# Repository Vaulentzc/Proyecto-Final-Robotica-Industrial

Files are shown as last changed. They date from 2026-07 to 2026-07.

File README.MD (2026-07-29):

<div align="center">
<picture>
    <source srcset="https://imgur.com/5bYAzsb.png" media="(prefers-color-scheme: dark)">
    <source srcset="https://imgur.com/Os03JoE.png" media="(prefers-color-scheme: light)">
    Escudo UNAL
</picture>

<h3>Curso de Robótica 2026-I</h3>

<h1>Proyecto Final - Robótica Industrial</h1>

<h2>Profesores: <br>Pedro Fabián Cárdenas Herrera <br> Manuel Felipe Carranza Montenegro<br></h2>

<p>
  
  
  
</p>

<br>
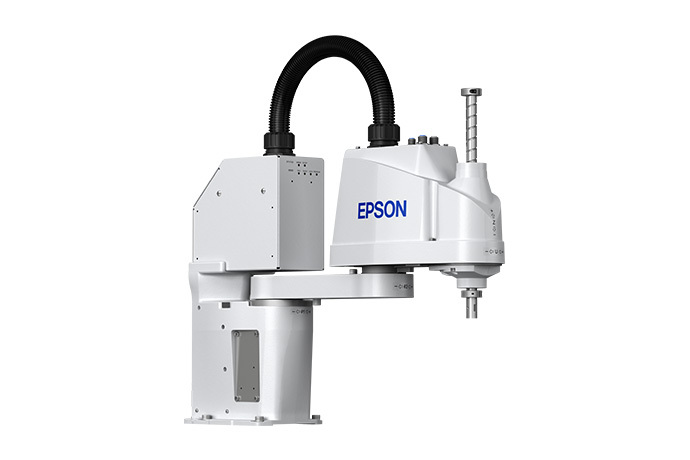
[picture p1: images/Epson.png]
Epson
<br>
<b>Figura 1. Manipulador industrial EPSON T3-401S.</b>
</div>

</div>

# Integrantes
1. Juan Andrés Moreno Benavides [jumorenobe@unal.co](Jumorenobe)
2. Mateo Ramos Cujer [mramoscu@unal.edu.co](MateoKGR)
3. Paula Valentina Alvarez Chaparro [palvarezch@unal.edu.co] (Vaulentzc)
4. Yesid Camilo Ojeda Hernández [yojeda@unal.edu.co] (YojedaMt)
5. David Felipe Cardenas Cubides [dcardenascu@unal.edu.co] (dcardenascu)

# Índice

1. [Bitácora del desarrollo](#1-bitácora-del-desarrollo)
2. [Diagrama de flujo del proceso global](#2-diagrama-de-flujo-del-proceso-global)
3. [Diseño del gripper](#3-diseño-del-gripper)
4. [Simulación](#4-simulación)
5. [Código fuente](#5-código-fuente)
6. [Comparación manual vs automatizado](#6-comparación-manual-vs-automatizado)
7. [Descripción detallada de la solución](#7-descripción-detallada-de-la-solución)
8. [Diagrama de flujo acciones del robot](#8-diagrama-de-flujo-acciones-del-robot)
9. [Plano de planta](#9-plano-de-planta)
10. [Videos demostrativos](#10-videos-demostrativos)

## 1. Bitácora del desarrollo

A continuación se documenta el proceso cronológico de diseño, simulación, fabricación e integración en laboratorio para el desarrollo de la **Etapa 2: Ensamblaje de Componentes** con el robot **Epson T3 401S ("Junior")**.

---

### Fase 1: Definición de Requerimientos y Diseño Mecánico

#### Definición de requerimientos

El objetivo principal de la herramienta es permitir la manipulación automática de componentes electrónicos mediante un brazo robótico, siendo capaz de recoger una pieza desde una ubicación determinada y depositarla en otra con la mayor precisión posible. Debido a que la aplicación está orientada al manejo de componentes para PCB, resulta especialmente importante mantener la orientación de la pieza durante todo el proceso, ya que una rotación indeseada dificultaría o impediría su colocación correcta.

A partir de estos objetivos se definieron los siguientes requerimientos de diseño:

- Ser capaz de levantar componentes electrónicos de diferentes tamaños.
- Poder activarse y desactivarse mediante una señal de control.
- Mantener la orientación del componente durante el transporte, en la medida de lo posible.
- Tener un diseño mecánico sencillo para facilitar tanto su fabricación como su integración con el brazo robótico.
- Minimizar la complejidad de la simulación y del sistema de control.

Con estos criterios se evaluaron distintas alternativas para la herramienta de agarre.

---

#### Alternativa 1: Ventosa de vacío

La primera opción considerada fue una **ventosa de vacío**, accionada mediante un sistema electroneumático. Esta alternativa presentaba la ventaja de que el laboratorio ya disponía de una herramienta funcional, reduciendo considerablemente el tiempo de diseño y fabricación.

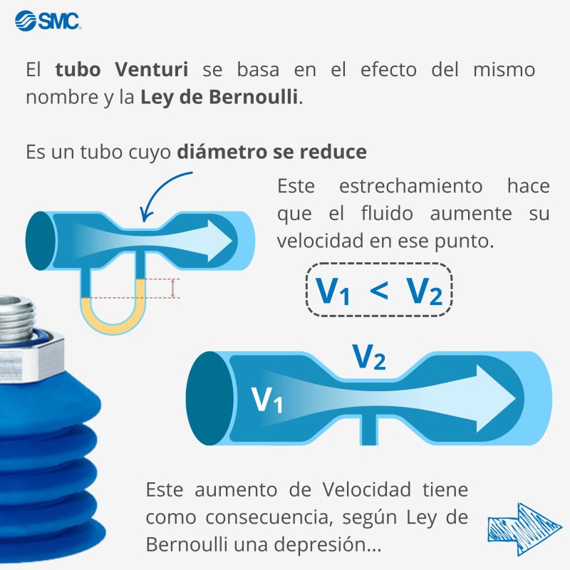
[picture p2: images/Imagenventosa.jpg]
Ventosa


Entre sus principales ventajas se encuentran:

- Diseño ya disponible y probado.
- Activación sencilla mediante electroválvulas.
- Integración relativamente simple con el sistema de control.
- Capacidad de manipular componentes de diferentes materiales.

Sin embargo, durante el análisis se identificaron varias limitaciones importantes para la aplicación propuesta.

La fuerza de succión se distribuye sobre una superficie relativamente amplia, lo que hace que el punto exacto de contacto dependa de la geometría de la pieza. Además, durante el momento en que la ventosa entra en contacto con el componente es frecuente que éste gire o cambie ligeramente de posición antes de quedar completamente adherido.

Como consecuencia, la orientación final del componente resulta poco repetible, lo cual representa una desventaja significativa cuando posteriormente debe colocarse sobre una PCB con una orientación específica.

Por estas razones, aunque la ventosa constituye una solución robusta para tareas generales de manipulación, no se consideró la alternativa más adecuada para este proyecto.

---

#### Alternativa 2: Electroimán

La segunda alternativa consistió en diseñar una herramienta basada en un **electroimán**.

Un electroimán funciona aprovechando el fenómeno del **electromagnetismo**: cuando una corriente eléctrica circula por una bobina, se genera un campo magnético capaz de atraer materiales ferromagnéticos. Al interrumpir la corriente, el campo desaparece prácticamente por completo, permitiendo liberar el componente de manera controlada.

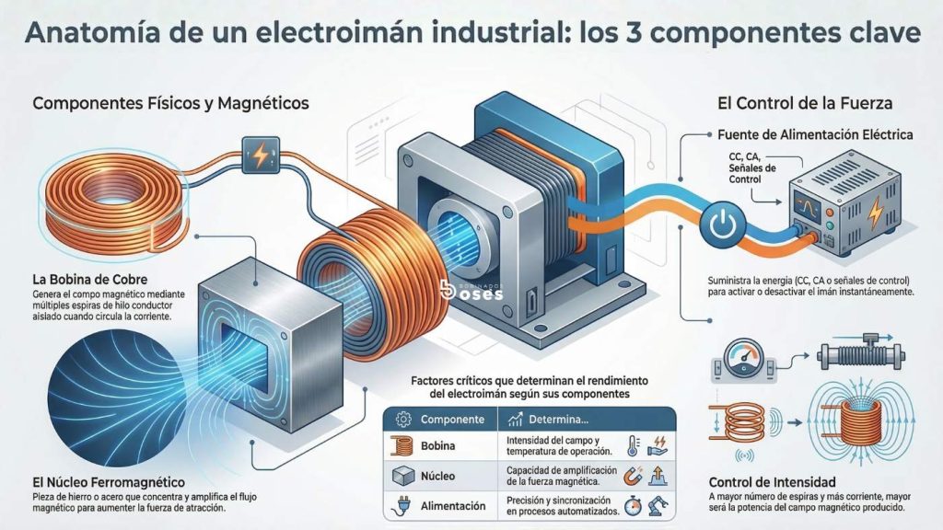
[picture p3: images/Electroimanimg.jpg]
Electroimán


Esta alternativa presentaba varias ventajas frente a la ventosa:

- Activación y desactivación mediante una simple señal eléctrica.
- Mayor precisión en el punto de contacto.
- Menor probabilidad de modificar la orientación del componente durante la recogida.
- Diseño compacto y fácilmente integrable al efector final del robot.
- Capacidad de sujetar componentes metálicos sin necesidad de generar vacío.

No obstante, también fue necesario considerar algunas desventajas:

- La herramienta debía diseñarse y fabricarse prácticamente desde cero.
- Requiere una corriente relativamente elevada para generar una fuerza de atracción suficiente.
- El calentamiento de la bobina produce un aumento de su resistencia eléctrica. Como consecuencia, la corriente disminuye y, con ella, la intensidad del campo magnético generado. Este fenómeno, conocido como **desmagnetización térmica** o **pérdida de fuerza por calentamiento**, provoca una reducción progresiva de la capacidad de sujeción mientras el electroimán permanece energizado.
- Si los componentes se encuentran demasiado próximos entre sí, el campo magnético puede atraer simultáneamente más de una pieza, por lo que es necesario mantener una separación adecuada durante el almacenamiento.

A pesar de estas limitaciones, las ventajas relacionadas con la precisión y el control de la orientación hicieron que esta alternativa resultara considerablemente más adecuada para los objetivos del proyecto.

---

#### Selección de la herramienta

Después de analizar ambas opciones se decidió implementar el **electroimán** como herramienta principal del brazo robótico.

Aunque implicaba un mayor trabajo de diseño y fabricación, esta solución ofrecía un mejor compromiso entre precisión, simplicidad del sistema de control y repetibilidad del proceso de manipulación, aspectos fundamentales para una aplicación orientada al ensamblaje de componentes electrónicos.

La selección del electroimán también hizo necesario diseñar un sistema de almacenamiento para los componentes. Este almacén debía mantener las piezas organizadas, suficientemente separadas para evitar capturas múltiples y con una disposición que facilitara el acceso del brazo robótico.

---

#### Diseño del almacén de componentes

Como complemento de la herramienta se diseñó una caja de almacenamiento que permite organizar los componentes electrónicos antes de ser manipulados.

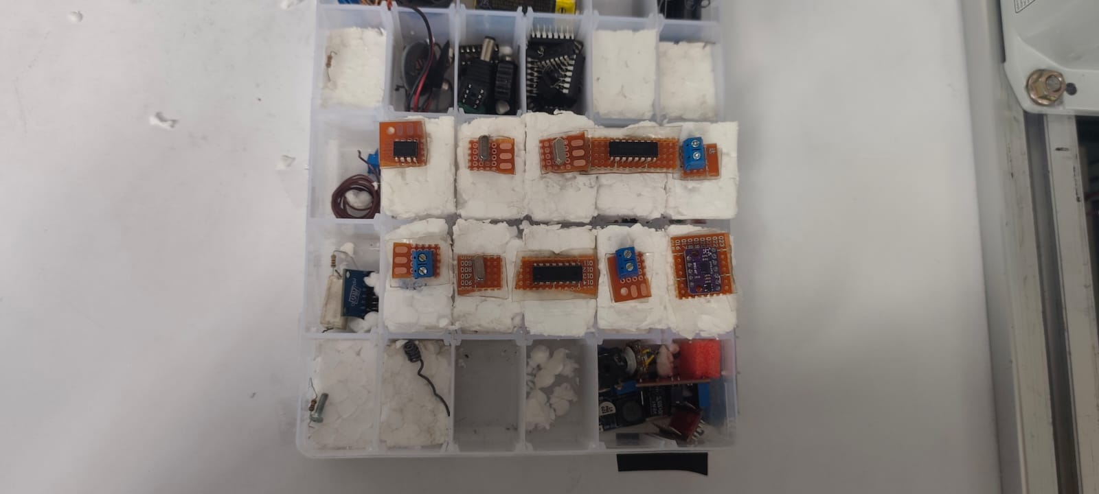
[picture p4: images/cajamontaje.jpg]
Foto de la caja


El diseño del almacén busca cumplir varios objetivos:

- Mantener las piezas ordenadas y fácilmente accesibles.
- Evitar que el campo magnético del electroimán capture más de un componente simultáneamente.
- Facilitar la identificación de la posición de cada componente durante la operación.
- Proporcionar una estructura estable para las pruebas experimentales.
- Permitir futuras ampliaciones del sistema para manejar un mayor número de referencias.

Con el diseño mecánico de la herramienta y del sistema de almacenamiento definidos, fue posible avanzar hacia las etapas de fabricación, caracterización del electroimán e integración con el sistema robótico.
> **[Agregen mas info]:** *Agregar especificaciones del material del gripper (impresión 3D PLA/PETG) y dimensiones exactas de la caja/almacén utilizada.*

---

### Fase 2: Programación Inicial y Simulación (EPSON RC+)
#### Desarrollo de código SPEL

Una vez definido el diseño mecánico de la herramienta, se desarrolló el programa de control utilizando el lenguaje **SPEL+** dentro del entorno **EPSON RC+**. El objetivo del software fue automatizar la secuencia completa de ensamblaje, desde la recogida de cada componente en el almacén hasta su colocación en la posición correspondiente de la baquela.

La implementación se estructuró en funciones independientes, permitiendo separar la configuración inicial, la definición de posiciones, la lógica de ensamblaje y el control del efector final. Esta organización facilita el mantenimiento del código y permite modificar cada parte del proceso sin afectar el funcionamiento general del programa.

##### Inicialización del robot

La rutina principal (`main`) es la encargada de preparar el robot antes de iniciar el proceso de ensamblaje. En esta etapa se realizan las siguientes acciones:

- Encendido de los motores.
- Configuración de potencia, aceleración y velocidad de trabajo.
- Retorno a la posición de referencia (*Home*).
- Carga de la información correspondiente a los componentes.
- Ejecución de la rutina principal de ensamblaje.
- Regreso a la posición de inicio una vez finalizado el proceso.

Esta estructura garantiza que el robot siempre comience y termine el ciclo desde una posición conocida y segura.

---

##### Organización de las posiciones

Para evitar programar manualmente cada movimiento del robot, se utilizaron dos arreglos globales:

- `alm(i)`: almacena la posición del componente dentro del almacén.
- `baq(i)`: almacena la posición destino sobre la baquela.

Cada índice representa un componente específico, de modo que ambos arreglos establecen una correspondencia directa entre el punto de recogida y el punto donde debe colocarse.

Por ejemplo, el componente almacenado en `alm(4)` será depositado automáticamente en la posición indicada por `baq(4)`.

Este método permite modificar la distribución física de los componentes simplemente cambiando los índices almacenados en las matrices, sin necesidad de alterar la lógica principal del programa.

---

##### Configuración automática mediante Pallet

En lugar de enseñar individualmente cada una de las posiciones del almacén y de la baquela, se utilizaron las herramientas de **paletizado** incluidas en EPSON RC+.

Se definieron dos mallas de trabajo:

- **Pallet 1:** almacén de componentes, organizado en una matriz de **6 × 6** posiciones.
- **Pallet 2:** baquela, organizada en una matriz de **27 × 22** posiciones.

Cada malla se genera automáticamente a partir de un punto de origen y dos vectores de referencia, permitiendo acceder a cualquier posición mediante un único índice.

Esta estrategia simplifica considerablemente la programación y facilita futuras modificaciones en la distribución de los componentes.

---

##### Secuencia de ensamblaje

La rutina `EnsambleComponentes` ejecuta el ciclo completo para cada uno de los componentes definidos.

Para cada elemento se realiza la siguiente secuencia:

1. Desplazamiento sobre la posición del componente en el almacén.
2. Descenso hasta la altura de recogida.
3. Activación del electroimán.
4. Asociación del componente CAD con la herramienta durante la simulación.
5. Elevación del componente.
6. Desplazamiento hasta la posición correspondiente de la baquela.
7. Descenso hasta la posición de inserción.
8. Desactivación del electroimán para liberar la pieza.
9. Fijación del componente en la simulación mediante el modelo CAD.
10. Elevación del robot para continuar con el siguiente componente.

Esta secuencia se ejecuta dentro de un ciclo `For`, permitiendo ensamblar automáticamente todos los componentes definidos por la variable `NumComponentes`.

---

##### Control del efector final

El accionamiento del electroimán se implementó mediante una salida digital del controlador.

Las funciones `Tomar` y `Soltar` encapsulan esta funcionalidad, permitiendo activar o desactivar el electroimán mediante una única instrucción desde la rutina principal.

Esta separación mejora la legibilidad del programa y facilita futuras modificaciones en caso de reemplazar el efector final por otro tipo de herramienta.

---

##### Integración con la simulación

Con el fin de representar correctamente el proceso dentro del entorno virtual, se implementaron las funciones `PickCAD` y `PlaceCAD`.

Estas funciones utilizan las instrucciones `SimSet` para asociar o liberar el modelo CAD correspondiente a cada componente durante las etapas de recogida y colocación. De esta manera, la simulación reproduce visualmente el comportamiento esperado del sistema sin afectar la lógica utilizada en la implementación real.

La utilización de procedimientos independientes para esta tarea permite desacoplar la simulación del control físico del robot, facilitando tanto las pruebas virtuales como la posterior implementación sobre el equipo real.

Video de la simulación con interfaz

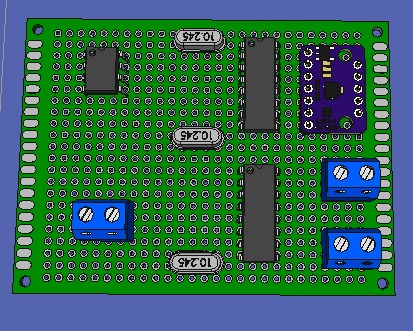
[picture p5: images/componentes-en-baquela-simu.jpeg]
Resultado de los componentes en la baquela de simulación


---

### Fase 3: Integración Hardware y Control Eléctrico

En esta fase se realizó la integración entre el robot, la herramienta de manipulación y el sistema de control eléctrico. Debido a que el electroimán requería un consumo de corriente superior al que podía suministrar directamente la salida del controlador del robot, fue necesario contar con el apoyo del profesor para diseñar una solución de alimentación adecuada. Para ello se implementó un sistema compuesto por dos fuentes de alimentación externas y un módulo relé, el cual permitía que el robot controlara el encendido y apagado del electroimán mediante una señal digital, aislando el circuito de potencia del circuito de control y garantizando un funcionamiento seguro.

Una vez completada la instalación eléctrica se realizaron pruebas de funcionamiento para verificar el correcto accionamiento del electroimán y la sincronización entre el movimiento del robot y la activación de la herramienta. Durante estas pruebas también se validaron los parámetros obtenidos previamente en el gemelo digital, comprobando que las posiciones de aproximación y recogida fueran alcanzables en el sistema físico sin generar colisiones.

La experimentación permitió identificar diversas limitaciones que no habían sido evidentes durante la etapa de simulación. En primer lugar, se determinaron con mayor precisión los límites del eje **Z**, estableciendo la distancia mínima y máxima de operación para garantizar una correcta captura de las piezas sin que la herramienta impactara contra la superficie de trabajo.

Adicionalmente, se observaron restricciones propias del hardware relacionadas con el comportamiento del electroimán durante periodos prolongados de operación. Debido al efecto Joule, la bobina incrementaba progresivamente su temperatura, provocando un aumento de su resistencia eléctrica y una reducción de la corriente que circulaba por ella. Como consecuencia, la fuerza magnética disponible disminuía con el tiempo, afectando directamente la capacidad de sujeción de las piezas.

Esta disminución de la fuerza de agarre produjo comportamientos diferentes dependiendo del tipo de componente manipulado y de su geometría. Algunas piezas eran levantadas correctamente, mientras que otras presentaban ligeros desplazamientos o rotaciones durante el transporte. Estas variaciones en la orientación final se acumulaban a lo largo del proceso y terminaron afectando la precisión del ensamblaje, especialmente en los últimos componentes de la PCB, donde las tolerancias de posicionamiento eran más estrictas.

Los resultados obtenidos en esta fase evidenciaron la importancia de considerar no solo las restricciones cinemáticas y geométricas del sistema, sino también los fenómenos eléctricos y térmicos asociados a la herramienta de manipulación. Estas pruebas permitieron ajustar los parámetros de operación y definir las limitaciones reales del sistema antes de realizar la integración completa del proceso de ensamblaje.

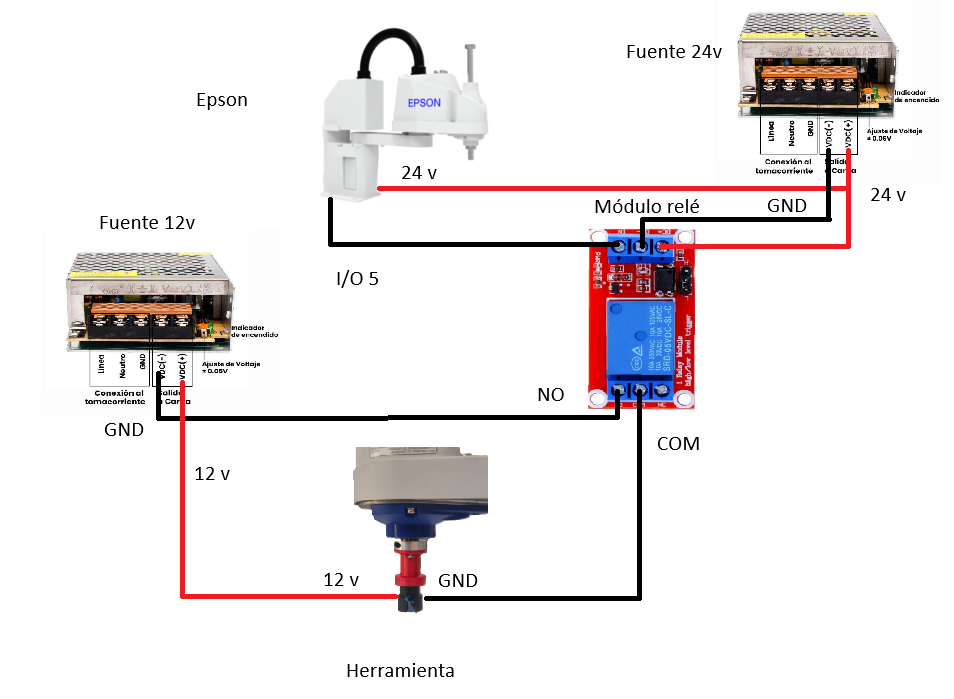
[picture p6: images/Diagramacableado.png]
Diagrama de cableado


---

### Fase 4: Pruebas en Laboratorio y Calibración de Trabajo (Iterativas)

Una vez validado el funcionamiento del programa en el entorno de simulación, se procedió a realizar la implementación sobre el robot físico. En esta etapa se evidenciaron diferencias importantes entre el modelo virtual y el sistema real, por lo que fue necesario realizar múltiples sesiones de prueba y calibración para garantizar un funcionamiento estable.

A diferencia de la simulación, en el montaje físico intervienen factores como las tolerancias mecánicas, pequeñas desviaciones en la ubicación de los componentes, variaciones en la herramienta de agarre y tiempos de respuesta de los actuadores, los cuales afectan directamente la precisión del proceso de ensamblaje.
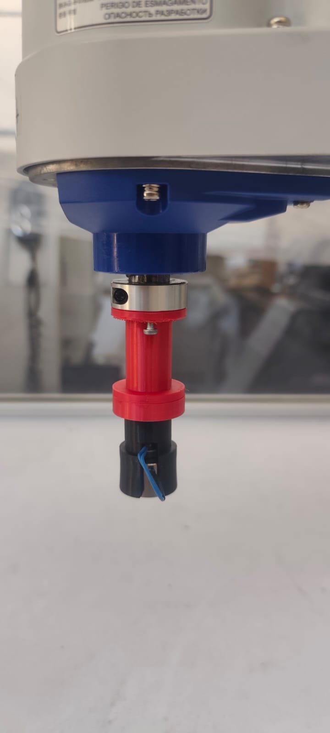
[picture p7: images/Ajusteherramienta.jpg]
Ajuste de herramienta

#### Calibración del sistema

La primera etapa consistió en la calibración del espacio de trabajo del robot. Para ello se definieron manualmente los puntos de referencia utilizados por las mallas de paletizado, verificando que las posiciones calculadas coincidieran con la ubicación real tanto del almacén de componentes como de la zona de ensamblaje.

Durante esta fase también se verificaron las dimensiones físicas del montaje y se realizaron pequeños ajustes sobre las coordenadas de referencia hasta obtener una correspondencia aceptable entre las posiciones programadas y las posiciones reales.

Posteriormente se ajustó la altura de seguridad utilizada durante los desplazamientos del robot. Este parámetro debía ser lo suficientemente elevado para evitar colisiones con los bordes del almacén, la baquela y otros elementos presentes en la estación de trabajo, pero sin incrementar innecesariamente el tiempo de ciclo.

#### Ajuste del proceso de manipulación

Una vez calibradas las posiciones, se realizaron pruebas repetitivas para optimizar la recogida y liberación de los componentes mediante el electroimán.

Se añadió físicamente a la caja una capa de icopor, esto para aprovechar mejor el posicionamiento del robot y añadir tolerancia de movimiento, pues el icopor amortigua el contacto y a la vez sostiene los elementos correctamente.

Se ajustó la altura final de aproximación para maximizar el contacto entre el electroimán y la superficie metálica de cada componente, incrementando así la fuerza efectiva de sujeción y reduciendo la probabilidad de desprendimiento durante el transporte, también se usaron diferentes alturas de recogida por la diferencia entre cada elemento.

Adicionalmente, se incorporaron tiempos de espera (`Wait`) en distintos puntos de la secuencia de movimiento. Aunque estos retardos aumentan ligeramente el tiempo total del ciclo, permiten que el robot complete cada movimiento antes de ejecutar la siguiente acción, mejorando la estabilidad del proceso y reduciendo errores ocasionados por pequeñas oscilaciones o tiempos de respuesta del sistema.

También se realizaron ajustes en la velocidad de los movimientos. El objetivo principal fue reducir el tiempo durante el cual el electroimán permanecía energizado, ya que se observó que un funcionamiento prolongado producía un calentamiento considerable de la bobina.

Este aumento de temperatura ocasionaba una disminución gradual de la fuerza magnética disponible, haciendo más probable que el componente se desprendiera durante el transporte. Como consecuencia, fue necesario encontrar un compromiso entre velocidad de desplazamiento, precisión del robot y tiempo máximo de activación del electroimán.
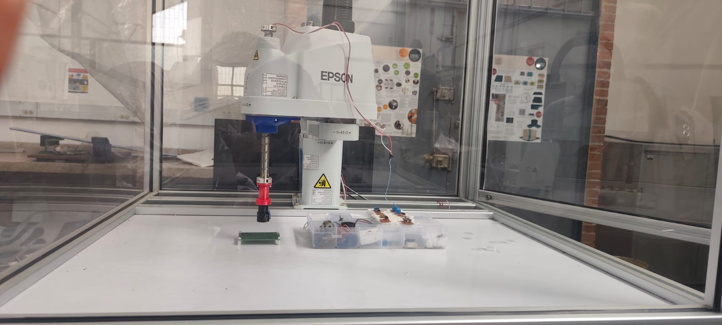
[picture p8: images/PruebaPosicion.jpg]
Pruebas de manipulación

#### Resultados y dificultades encontradas

Durante las pruebas experimentales también se observó que el comportamiento del sistema dependía considerablemente del tipo de componente manipulado.

Las piezas con mayor superficie metálica presentaban un agarre más estable, mientras que componentes pequeños o con menor área de contacto requerían una alineación mucho más precisa para ser levantados correctamente.

Otro aspecto importante identificado durante la experimentación fue la pérdida de orientación de varios componentes durante la fase de recogida y transporte. Aunque el electroimán proporciona un punto de agarre más localizado que una ventosa de vacío, la fuerza magnética no restringe completamente la rotación de la pieza, por lo que pequeños impactos o vibraciones podían modificar su orientación.

Esta situación resultó especialmente crítica al intentar depositar los componentes directamente sobre una PCB, ya que incluso pequeñas variaciones angulares impedían que las piezas coincidieran correctamente con su posición de montaje.

Como resultado de estas pruebas, se decidió utilizar una superficie de depósito plana durante la validación experimental en lugar de realizar el ensamblaje directamente sobre la tarjeta electrónica. Esta decisión permitió evaluar el funcionamiento general del sistema sin introducir errores adicionales asociados a la orientación de los componentes.

También se usó una capa extra compuesta de baquelas recortadas para poder añadir consistencia de posiciones y asi buscar mas precisión de agarre de el electroimán.

Finalmente, las pruebas permitieron identificar las principales limitaciones del efector final basado en un electroimán. Si bien la herramienta demostró ser adecuada para la manipulación automática de componentes electrónicos, la pérdida progresiva de fuerza debido al calentamiento y la dificultad para garantizar una orientación constante representan aspectos que deberán abordarse en futuras iteraciones del diseño.

### Evidencias del Desarrollo

| Hito / Actividad | Descripción | Evidencia Fotográfica / Video |
| :--- | :--- | :---: |
| **Diseño CAD Herramienta** | Modelo 3D del soporte para el electroimán. | |
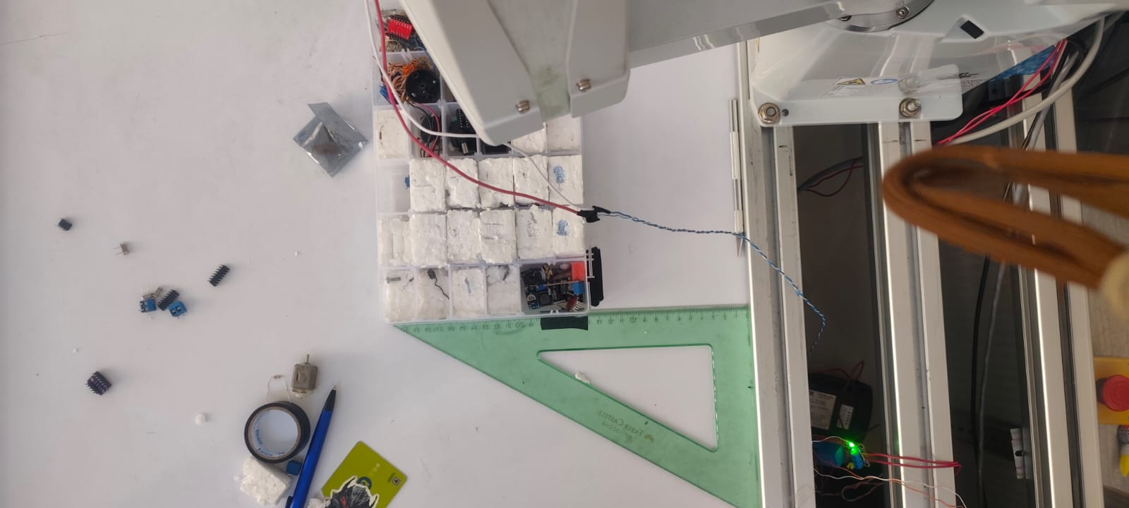
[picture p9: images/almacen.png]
Almacen
| **Acondicionamiento Almacén** | Caja seleccionada con componentes ordenados. | ** |
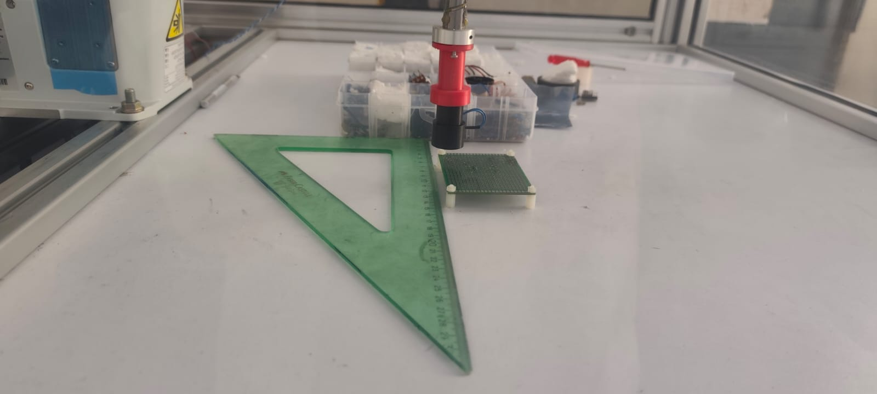
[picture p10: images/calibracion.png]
Calibracion
| **Calibración en Lab** | Ajuste de puntos de paletizado en el Epson T3. | ** |
| **Prueba de Agarre** | Verificación de sujeción electromagnética (`DO_09`). | |

---

## 2. Diagrama de flujo del proceso global

El proceso global de la línea automatizada consta de cuatro estaciones robotizadas secuenciales e independientes para la manufactura, ensamble, soldadura y empaque de tarjetas electrónicas (PCBs).

```mermaid
flowchart TD
    %% Inicio del sistema
    START([Inicio del Proceso Global]) --> HMI_INIT[Selección de Receta y Start en HMI]
    
    %% ETAPA 1
    subgraph E1["Etapa 1: Clasificación y Ordenamiento (ABB IRB 140 - Caín)"]
        E1_IN[Llegada de componentes en desorden por banda transportadora] --> E1_VIS["Visión Artificial (Kinect + MATLAB):<br/>Detección e Identificación de Tipo/Pose"]
        E1_VIS --> E1_PICK[Pick de componente en banda]
        E1_PICK --> E1_DEC{¿Clasificación exitosa?}
        E1_DEC -- Sí --> E1_PLACE[Place en celda correspondiente del Almacén Ordenado]
        E1_DEC -- No / Duda --> E1_REJ[Depositar en Bandeja de Rechazo / Alarma HMI]
        E1_PLACE --> E1_COUNT[Incrementar Conteo por Tipo]
        E1_COUNT --> E1_CHECK{¿Almacén Completo?<br/>N >= 30 componentes}
        E1_CHECK -- No --> E1_IN
        E1_CHECK -- Sí --> E1_READY[Señal: Almacén Listo / Transfiriendo]
    end

    HMI_INIT --> E1_IN

    %% ETAPA 2
    subgraph E2["Etapa 2: Ensamblaje en PCB (Epson T3 401S - Junior)"]
        E2_SETUP[Fijar PCB en Fixture de Estación Epson] --> E2_RECIP[Cargar Receta de Posiciones X, Y, Ángulo]
        E2_RECIP --> E2_LOOP_INIT[Inicializar i = 1]
        E2_LOOP_INIT --> E2_LOOP_CHK{¿i <= N_componentes?}
        E2_LOOP_CHK -- Sí --> E2_PICK[Pick desde Almacén Ordenado con Electroimán]
        E2_PICK --> E2_PLACE[Jump Place/Inserción en coordenadas destino en PCB]
        E2_PLACE --> E2_INC[i = i + 1]
        E2_INC --> E2_LOOP_CHK
        E2_LOOP_CHK -- No --> E2_VERIF[Inspección Visual Rápida / Foto Final]
        E2_VERIF --> E2_READY[Señal: PCB Poblada / Transfiriendo]
    end

    E1_READY --> E2_SETUP

    %% ETAPA 3
    subgraph E3["Etapa 3: Soldadura (Yaskawa Motoman MH6 - El Chambeador)"]
        E3_SETUP[Fijar PCB Poblada en Fixture de Soldadura] --> E3_PATH[Cargar Rutina y Patrón de Puntos P1..PN]
        E3_PATH --> E3_EXEC[Ejecución de Trayectoria de Soldadura / Puntos]
        E3_EXEC --> E3_LOG[Generación de Log de Registro Explicito]
        E3_LOG --> E3_READY[Señal: PCB Soldada / Transfiriendo]
    end

    E2_READY --> E3_SETUP

    %% ETAPA 4
    subgraph E4["Etapa 4: Empaque y Envío (ABB IRB 140 - Abel)"]
        E4_PICK[Pick de PCB Soldada desde Estación 3] --> E4_PACK[Colocar en Caja/Bandeja de Empaque]
        E4_PACK --> E4_LABEL[Colocar Etiqueta de Lote]
        E4_LABEL --> E4_BELT[Depositar en Banda Transportadora de Salida]
        E4_BELT --> E4_COUNT[Incrementar Contador de Producción en HMI]
    end

    E3_READY --> E4_PICK
    E4_COUNT --> END([Fin del Proceso - Producto Empacado])

    %% Estilos de Nodos
    style START fill:#4CAF50,stroke:#333,stroke-width:2px,color:#fff
    style END fill:#2196F3,stroke:#333,stroke-width:2px,color:#fff
    style E1 fill:#FFF3E0,stroke:#FF9800,stroke-width:2px
    style E2 fill:#E8F5E9,stroke:#4CAF50,stroke-width:2px
    style E3 fill:#E1F5FE,stroke:#03A9F4,stroke-width:2px
    style E4 fill:#F3E5F5,stroke:#9C27B0,stroke-width:2px
```

## 3. Diseño del gripper

Se diseño el gripper para los componentes electronicos en torno a un sistema electromagnetico con un electroiman de referencia  P 20/15 facilitado por el profesor , a continuación la siguiente tabla muestra diferentes referencias de electroimanes y sus caracteritisticas :

| Modelo | Diámetro ($\varnothing$) | Altura ($H$) | Fuerza de Sujeción | Potencia Aprox. | Corriente (a 12V) | Rosca de Montaje |
| :--- | :---: | :---: | :---: | :---: | :---: | :---: |
| **P20/15** | 20 mm | 15 mm | 2.5 – 3.0 kg (25–30 N) | ~3 W | ~0.25 A | M3 / M4 |
| **P25/11** | 25 mm | 11 mm | 5.0 kg (50 N) | ~2 W | ~0.17 A | M4 |
| **P25/20** | **25 mm** | **20 mm** | **5.0 – 8.0 kg (50–80 N)** | **2 W – 3.6 W** | **~0.17 A – 0.30 A** | **M4** |
| **P30/22** | 30 mm | 22 mm | 10.0 – 15.0 kg (100–150 N) | ~4 W | ~0.33 A | M4 |
| **P34/25** | 34 mm | 25 mm | 20.0 – 25.0 kg (200–250 N) | ~5 W | ~0.42 A | M4 / M5 |
| **P40/20** | 40 mm | 20 mm | 25.0 – 30.0 kg (250–300 N) | ~8 W | ~0.67 A | M5 |

Con base a sus caracteristicas fisicas y a una herramienta previamente enseñada como inspiraciòn se procedio a hacer el soporte de dicho electroiman, a continuacón se presenta dicho gripper encontrado en el robot :

<p align="center">
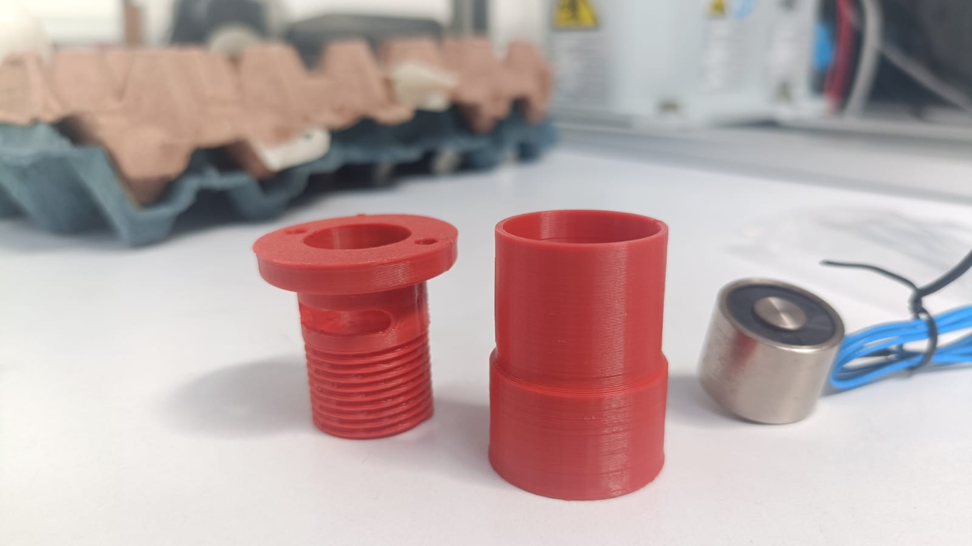
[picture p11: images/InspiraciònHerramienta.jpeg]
InspiraciònHerramienta
  
</p>

Tambien se presentan las imagenes del electroiman utilizado :

<p  align="center">
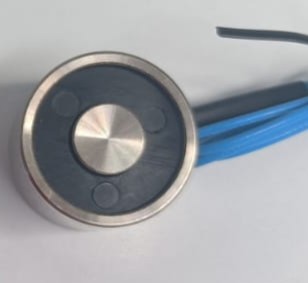
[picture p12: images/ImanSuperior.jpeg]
ImanSuperior
  
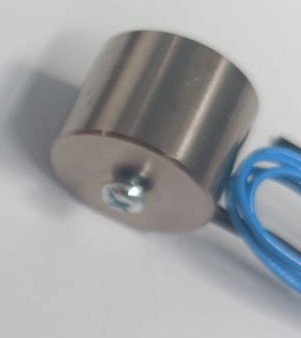
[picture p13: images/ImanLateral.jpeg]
imagesImanLateral
  
</p>

El diseño se inspiro de igual forma en otra herramienta previamente instalada en el robot para el diseño de la primera parte atornillada : 

<p  align="center">
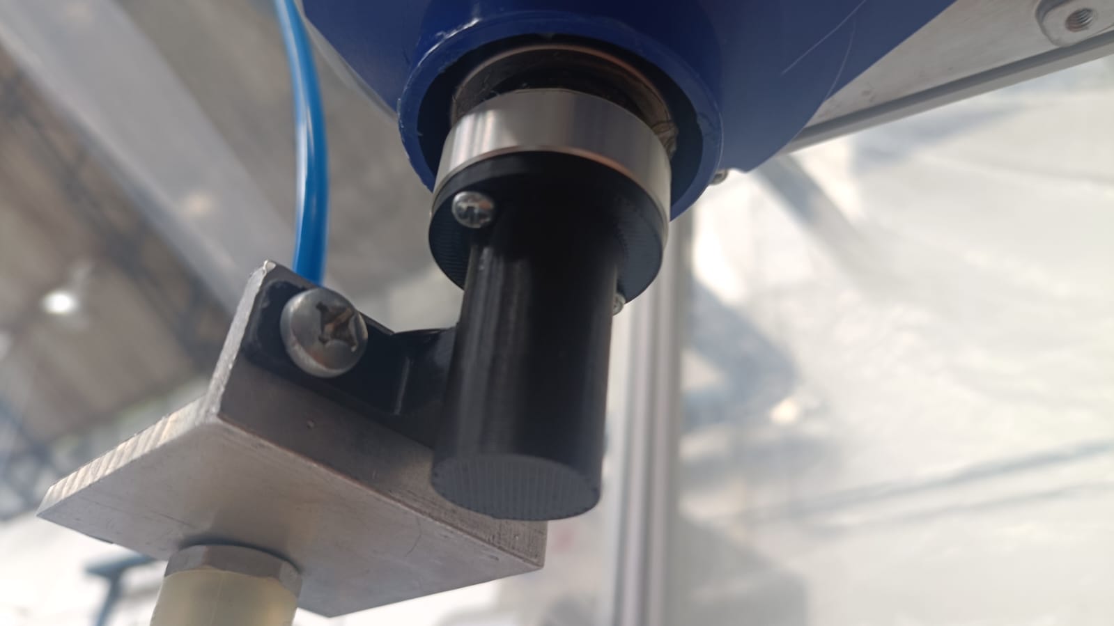
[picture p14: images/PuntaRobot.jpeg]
PuntaRobot
  
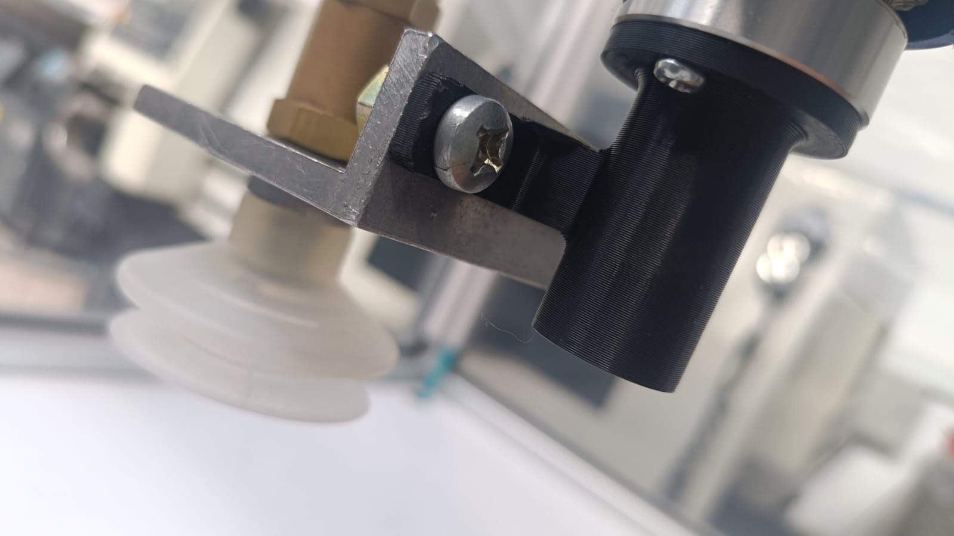
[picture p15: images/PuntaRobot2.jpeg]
PuntaRobot
  
</p>

Observando el diseño, se optó por realizar un ensamblaje de dos partes: una fija a la punta del robot atornillada a este, con un orificio en la punta por donde se acoplaría la otra parte por rosca y pasaría el cable del electroimán conectado a su circuito de control por dentro del tornillo sin fin aprovechando su espacio hueco. Se realiza en dos partes para facilitar el ensamblaje rápido de este, y así agilizar tiempos de desacople y acople en realizaciones futuras por posibles fallos, entre otros motivos.

A continuación se muestran imágenes de las partes del ensamblaje de Inventor con su respectivo modelado del electroimán y las dos partes de acople por rosca; de igual forma, se muestra el ensamblaje final 

<p  align="center">
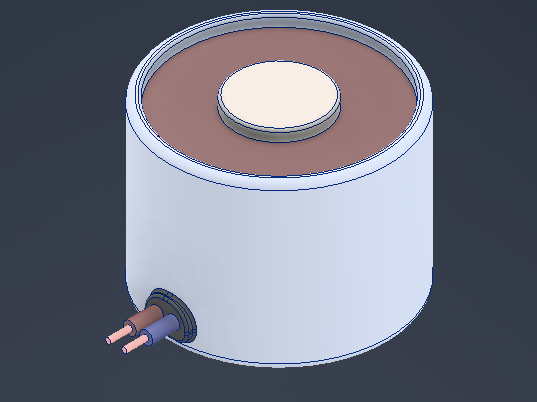
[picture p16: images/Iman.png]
  
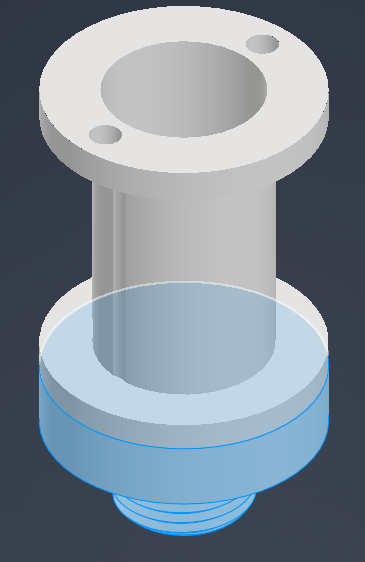
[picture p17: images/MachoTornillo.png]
  
</p>

<p  align="center">
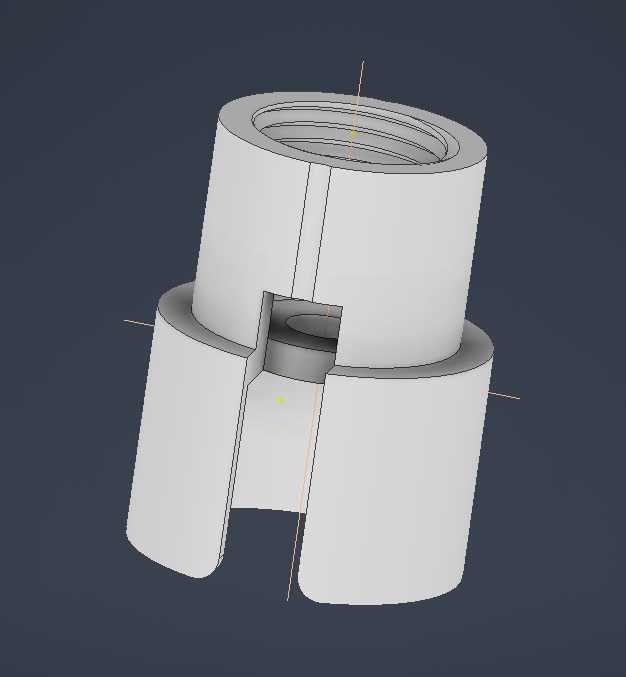
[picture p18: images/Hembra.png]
Hembra
  
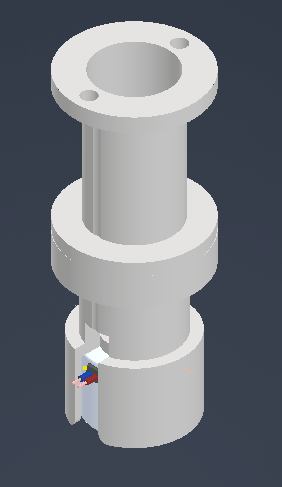
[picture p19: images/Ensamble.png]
Ensamble
  
</p>

Se presenta tambien su manufactura en impresión 3D ya atornillada a la punta del robot como su versión final y despegado de este para ver la sección interna y su cable  :

<p  align="center">
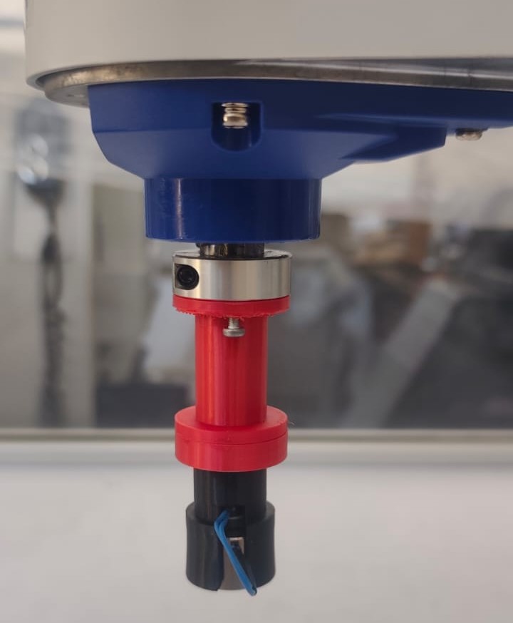
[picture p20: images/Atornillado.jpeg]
Atornillado
  
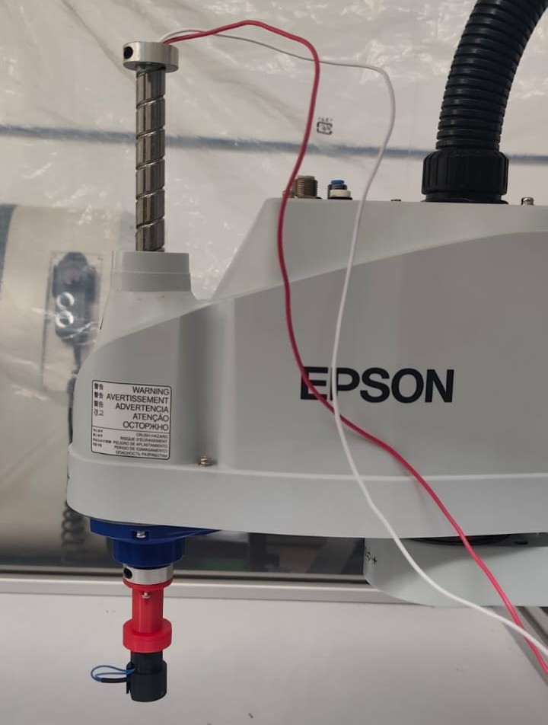
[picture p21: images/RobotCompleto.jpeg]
RobotCompleto
  
</p>

<p align="center">
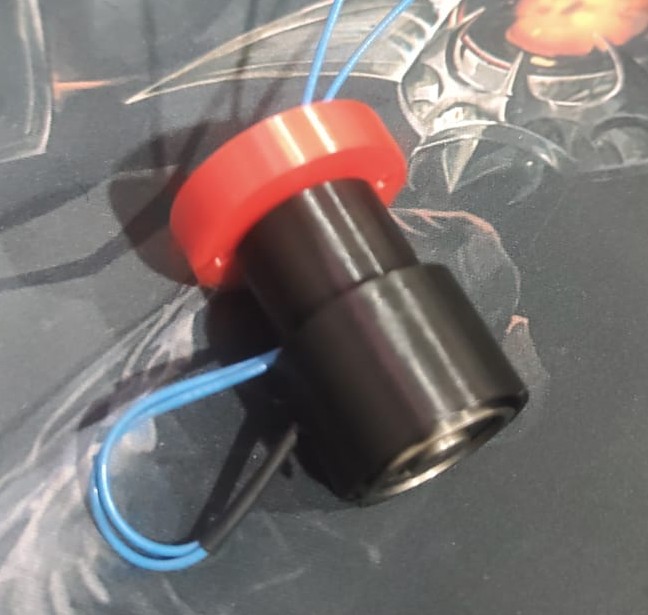
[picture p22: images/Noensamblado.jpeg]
Noensamblado
  
</p>

## 4. Simulación
En el siguiente video se encuentra el desarrollo de la simulación con la interfaz 

[Video de muestra de la simulación](https://drive.google.com/file/d/1aKwmYIPQHjhY68W_krXGP0N0tfTiAC5Q/view?usp=drive_link)

Se muestra el resultado de los componentes en la baquela

Resultado componentes en la baquela en la simulación

## 5. Código fuente
El control y automatización de la **Etapa 2: Ensamblaje de Componentes** ejecutada por el robot **Epson T3 401S ("Junior")**  se desarrolló en el entorno **EPSON RC+** empleando el lenguaje de programación **SPEL+**. 

A continuación se detalla la estructura y funcionamiento del código implementado para la manipulación y posicionamiento de componentes mediante el electroimán adaptado.

### Estructura del Código

#### 1. Declaración de Variables Globales
```i```: Variable de control para los iteradores en los bucles de ensamble.
```alm(20)```: Arreglo que almacena las posiciones relativas (índices) de cada componente dentro del almacén ordenado.
```baq(20)```: Arreglo que asigna la posición relativa destino dentro de la tarjeta electrónica (baquela/PCB).
NumComponentes: Determina el número total de piezas a manipular durante la ejecución.

### 2. Rutina Principal (main)
Es el punto de entrada del programa. Establece la configuración de seguridad, velocidad del manipulador y coordina la secuencia global del ciclo de trabajo.
```Power High / Accel / Speed```: Habilita la máxima potencia y fija las velocidades e inercias al 100% para optimizar el tiempo de ciclo.
```Home```: Envía el robot a su posición segura inicial y final para prevenir colisiones durante el encendido o parada.
Llamado a subrutinas: Ejecuta de manera secuencial la asignación de posiciones y el proceso de pick & place.

### 3. Mapeo de Componentes (CargarComponente)
Define la relación entre el origen (almacén) y el destino (baquela) para cada ítem de la receta de ensamble.

### 4. Proceso de Ensamble y Paletizado (EnsambleComponentes)
Configura las mallas de trabajo (pallets) y ejecuta la rutina iterativa de Pick & Place utilizando trayectorias arqueadas para garantizar la seguridad en la inserción.

```Pallet 1```: Define la rejilla del Almacén con una matriz de $6 \times 2$ posiciones.
```Pallet 2```: Define la rejilla de la Baquela con una matriz de $27 \times 22$ posiciones.
```Jump```: Ejecuta un movimiento tipo SCARA Gate (eleva el eje Z, desplaza X/Y y baja Z), evitando obstáculos intermedios entre la zona de almacenamiento y la PCB.

### 5. Control del Actuador Final (Tomar / Soltar)
Gestión del efector final (electroimán) a través de salidas digitales del controlador Epson.

```DO_09```: Salida digital conectada al relé de activación del electroimán. Funciona bajo lógica invertida (o normalmente cerrado según el arreglo físico del relé):
```Off DO_09```: Energiza/activa la sujeción electromagnética para tomar el componente.
```On DO_09```: Desenergiza la herramienta para liberar el componente sobre la PCB.

## 6. Comparación manual vs automatizado

Con el fin de evaluar el impacto de la solución desarrollada, se realizó una comparación entre el proceso de ensamblaje manual de componentes y el proceso automatizado implementado mediante el robot **EPSON T3-401S** equipado con un efector final electromagnético.

Aunque el sistema desarrollado corresponde a un prototipo de laboratorio y no a una línea de producción industrial completamente optimizada, permitió identificar las principales ventajas y limitaciones de la automatización para este tipo de tareas.

| Aspecto | Ensamblaje manual | Ensamblaje automatizado |
|---------|-------------------|-------------------------|
| Repetibilidad | Depende del operador y puede variar entre ciclos. | Alta repetibilidad una vez calibrado el sistema. |
| Precisión de posicionamiento | Depende de la habilidad del operario. | Determinada por la precisión del robot y la correcta calibración de las posiciones. |
| Fatiga del operador | Aumenta con el tiempo y puede generar errores. | No existe fatiga durante la operación automática. |
| Flexibilidad | Permite reaccionar fácilmente ante componentes mal ubicados. | Requiere recalibración o reprogramación para cambios importantes en la disposición de las piezas. |
| Tiempo de operación | Variable entre operadores. | Constante para cada ciclo de trabajo. |
| Riesgo de errores humanos | Alto en tareas repetitivas. | Bajo, dependiendo de la correcta programación y calibración del sistema. |
| Costos iniciales | Bajos. | Elevados debido al robot, controlador y herramienta especializada. |
| Producción continua | Limitada por el operador. | Puede operar continuamente dentro de las limitaciones del sistema. |

### Análisis de resultados

Durante las pruebas realizadas se observó que el robot ejecuta la misma trayectoria en cada ciclo con una elevada repetibilidad, una de las principales ventajas frente al ensamblaje manual. Una vez calibradas las posiciones del almacén y de la zona de trabajo, el sistema fue capaz de repetir la secuencia de recogida y depósito sin intervención del operador.

Sin embargo, también se identificaron limitaciones asociadas principalmente al efector final. A diferencia de un gripper mecánico, el electroimán no restringe completamente la orientación del componente, por lo que pequeñas vibraciones durante el transporte pueden producir ligeras rotaciones que dificultan su colocación exacta sobre la PCB.

Adicionalmente, el calentamiento de la bobina durante periodos prolongados de funcionamiento reduce progresivamente la fuerza magnética disponible, disminuyendo la confiabilidad del agarre en ciclos continuos. Este comportamiento únicamente pudo observarse durante las pruebas experimentales y no fue evidente en la etapa de simulación.

En términos generales, el proyecto permitió demostrar que la automatización mejora significativamente la repetibilidad del proceso y reduce la dependencia del operador, aunque el desempeño final continúa estando condicionado por el diseño del efector final y las características de los componentes manipulados.
## 7. Descripción detallada de la solución

La solución desarrollada corresponde a una estación automatizada para el ensamblaje de componentes electrónicos utilizando un robot **EPSON T3-401S (Junior)** equipado con un efector final basado en un electroimán. Esta estación constituye la segunda etapa de una línea automatizada de manufactura de tarjetas electrónicas (PCB) y tiene como objetivo recoger componentes previamente organizados en un almacén y posicionarlos automáticamente en las ubicaciones definidas sobre la tarjeta.

### Arquitectura del sistema

La estación está conformada por cuatro subsistemas principales:

- **Robot industrial EPSON T3-401S**, encargado de realizar los movimientos de manipulación.
- **Efector final electromagnético**, diseñado e impreso en 3D para sujetar componentes metálicos.
- **Sistema de alimentación y control eléctrico**, compuesto por dos fuentes externas y un módulo relé que permite controlar el electroimán desde las salidas digitales del robot.
- **Software desarrollado en EPSON RC+ mediante SPEL+**, responsable de coordinar toda la secuencia automática de ensamblaje.

La integración de estos subsistemas permite ejecutar de forma automática el proceso completo de **Pick & Place**, desde la recogida del componente hasta su deposición en la posición correspondiente de la PCB.

### Funcionamiento del proceso

El ciclo automático inicia con el robot ubicado en la posición **Home**, donde se habilitan los motores y se configuran los parámetros de velocidad, aceleración y potencia.

Posteriormente se cargan las posiciones de los componentes mediante dos arreglos:

- **alm(i):** almacena la posición de cada componente dentro del almacén.
- **baq(i):** almacena la posición destino correspondiente sobre la PCB.

Una vez cargada la información, el robot ejecuta un ciclo repetitivo para cada componente:

1. Desplazamiento mediante una trayectoria tipo **Jump** hasta el almacén.
2. Descenso a la altura de captura.
3. Activación del electroimán mediante la salida digital **DO_09**.
4. Elevación del componente.
5. Desplazamiento hacia la posición correspondiente en la PCB.
6. Descenso hasta la altura de colocación.
7. Desactivación del electroimán para liberar la pieza.
8. Retorno a una altura segura para iniciar el siguiente ciclo.

Al finalizar el ensamblaje de todos los componentes, el robot retorna nuevamente a la posición **Home**, concluyendo el proceso automático.

### Organización del espacio de trabajo

Con el fin de simplificar la programación, las posiciones del almacén y de la tarjeta electrónica fueron definidas mediante las herramientas de **Pallet** disponibles en EPSON RC+.

Se configuraron dos mallas independientes:

- **Pallet 1:** almacén de componentes.
- **Pallet 2:** posiciones de montaje sobre la PCB.

Esta estrategia permite modificar la distribución física de las piezas sin alterar la lógica principal del programa, ya que únicamente es necesario actualizar los puntos de referencia de cada malla.

### Sistema de agarre

La herramienta de manipulación consiste en un electroimán montado sobre un soporte diseñado en Autodesk Inventor e impreso mediante manufactura aditiva.

El soporte está conformado por dos piezas ensambladas mediante una unión roscada, lo que facilita el montaje, mantenimiento y reemplazo de la herramienta. Además, el diseño permite conducir el cableado del electroimán por el interior del soporte hasta el circuito de control, mejorando la protección mecánica y el acabado del conjunto.

El accionamiento del electroimán se realiza mediante un módulo relé controlado por una salida digital del robot, mientras que la alimentación eléctrica es suministrada por fuentes externas debido a que la corriente requerida supera la capacidad del controlador del robot.

### Interfaz de operación

Con el propósito de facilitar la interacción con la estación se desarrolló una interfaz HMI utilizando el **GUI Builder** de EPSON RC+.

Desde esta interfaz el operador puede iniciar o detener el ciclo automático, enviar el robot a la posición Home, reiniciar el sistema después de una falla y supervisar el estado del proceso mediante indicadores que muestran el componente procesado, el avance del ensamblaje y los posibles mensajes de alarma.

### Integración y validación

La implementación experimental permitió validar el funcionamiento conjunto del sistema mecánico, eléctrico y de control.

Durante las pruebas fue necesario calibrar las posiciones del almacén, ajustar diferentes alturas de aproximación para cada componente e incorporar tiempos de espera que mejoraron la estabilidad del proceso. Asimismo, se comprobó que el calentamiento progresivo del electroimán disminuye la fuerza de sujeción disponible, representando la principal limitación del sistema desarrollado.

En conjunto, la solución implementada demuestra la viabilidad de automatizar el proceso de ensamblaje de componentes electrónicos mediante un robot SCARA, integrando diseño mecánico, control eléctrico, programación industrial e interfaz de supervisión en una única estación de trabajo.
## Diseño HMI

La interfaz HMI desarrollada para la estación de ensamblaje con el robot Epson T3 401S fue diseñada con el objetivo de facilitar la operación y supervisión del proceso de ensamblaje de componentes sobre la PCB.

El diseño se realizó en el apartado de GUI Builder de EPSON RC+, buscando una interfaz simple, clara y orientada a mostrar únicamente la información necesaria para el operador. para lo cual se uso:

### Elementos de la HMI – Epson T3 401S

| Nombre del elemento | Tipo | Función | Comportamiento / información mostrada |
|---|---|---|---|
| `btnStart` | Botón | Iniciar el ciclo automático de ensamble | Ejecuta la rutina `TareaEnsamble` en la Task 5 si no existe un ciclo en ejecución. |
| `btnStop` | Botón | Detener el ciclo de ensamble | Finaliza la Task 5 y desactiva la salida `DO_09` correspondiente al sistema de agarre. |
| `btnHome` | Botón | Llevar el robot a la posición Home | Solo permite ejecutar `Home` cuando no existe un ciclo de ensamble en ejecución. |
| `tbnReset` | Botón | Restablecer el sistema después de una falla o parada | Ejecuta `Reset`, desactiva `DO_09` y devuelve los indicadores de la HMI a un estado inicial. |
| `lblEstado` | Label dinámico | Mostrar el estado general de la estación | Puede mostrar estados como `IDLE`, `RUN`, `FAULT` y `DONE`. |
| `lblOperacion` | Label dinámico | Mostrar la operación que está realizando actualmente el robot | Muestra mensajes como `Ejecutando HOME`, `Realizando PICK`, `Trasladando componente`, `Realizando PLACE` o `Ensamble finalizado`. |
| `lblComponente` | Label dinámico | Indicar el componente que se está procesando | Muestra el número del componente actual, por ejemplo: `Componente actual: 4`. |
| `lblProgreso` | Label dinámico | Mostrar el avance del ensamble | Indica la cantidad de componentes colocados respecto al total, por ejemplo: `Progreso: 6 / 10`. |
| `lblReceta` | Label informativo | Mostrar la receta de ensamble seleccionada | Identifica la PCB o receta actualmente cargada, por ejemplo: `Receta: PCB-01`. |
| `lblAlarma` | Label dinámico | Mostrar alarmas, advertencias o condiciones anormales | Normalmente muestra `Alarma: Sin alarmas`; puede indicar ciclo ya iniciado, proceso detenido, imposibilidad de ejecutar Home u otras fallas. |

teniendo como resultado final:

<br>
<div align="center">
  <img src="images/HMI.png" alt="manual" style="border-radius: 5px; width: 350px;">
  <br>
  <b>Figura 5. Diseño de HMI.</b>
</div>
<br>

## 8. Diagrama de flujo acciones del robot
El siguiente diagrama detalla la secuencia algorítmica y la toma de decisiones que ejecuta el robot  durante la **Etapa 2: Ensamblaje de Componentes**, reflejando la lógica programada en **SPEL+**:

```mermaid
flowchart TD
    A([Inicio: main]) --> B[Habilitar Motores: Motor On]
    B --> C[Configurar Dinámica: Power High, Speed 100, Accel 100, 100]
    C --> D[Mover a Posición de Seguridad: Home]
    
    D --> E[Ejecutar: CargarComponentes]
    E --> F[Definir NumComponentes]
    F --> G[Mapear Arreglos: alm i -> Posición Almacén<br/>baq i -> Posición Baquela]
    
    G --> H[Ejecutar: EnsambleComponentes]
    H --> I["Configurar Rejillas:<br/>Pallet 1 (Almacén 6x2)<br/>Pallet 2 (Baquela 27x22)"]
    I --> J[Inicializar Contador: i = 1]
    
    J --> K{¿i <= NumComponentes?}
    
    K -- Sí --> L["Jump Pallet(1, alm(i))<br/>Desplazamiento tipo arco a la celda del almacén"]
    L --> M[Wait 1s]
    M --> N["Call Tomar<br/>Off DO_09 (Energiza Electroimán)"]
    N --> O[Wait 1s]
    
    O --> P["Jump Pallet(2, baq(i))<br/>Desplazamiento tipo arco hacia la PCB"]
    P --> Q[Wait 1s]
    Q --> R["Call Soltar<br/>On DO_09 (Desenergiza Electroimán)"]
    R --> S[Wait 1s]
    
    S --> T[Incrementar: i = i + 1]
    T --> K
    
    K -- No --> U[Mover a Posición Final: Home]
    U --> V([Fin del Programa: Fend])

    %% Estilos visuales del diagrama
    style A fill:#4CAF50,stroke:#333,stroke-width:2px,color:#fff
    style V fill:#F44336,stroke:#333,stroke-width:2px,color:#fff
    style K fill:#FF9800,stroke:#333,stroke-width:2px,color:#fff
    style N fill:#2196F3,stroke:#333,stroke-width:2px,color:#fff
    style R fill:#9C27B0,stroke:#333,stroke-width:2px,color:#fff

```

## 9. Plano de planta

Se eseña el plano de planta del robot y la posición del almacen y la pcb 

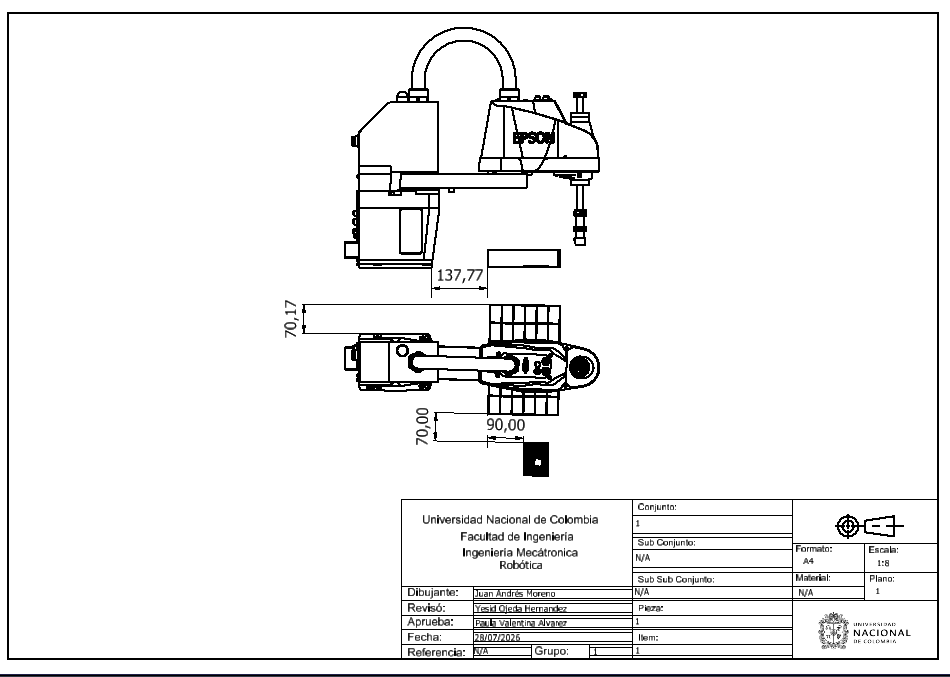
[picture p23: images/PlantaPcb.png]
Foto Plano de Planta


## 10. Videos demostrativos

A continuación se muestran los videos de la implementación fisica final 

<p align="center">
  <b>
    Video de implentación Final fisica 1 (Prueba sin pcb , velocidad X2)
      
  </b><br>
</p>

<p align="center">
  <a href="https://drive.google.com/file/d/1OsyPAgnnxUSs0Gmu0NFNt79tbQhQKWB3/view?usp=sharing">
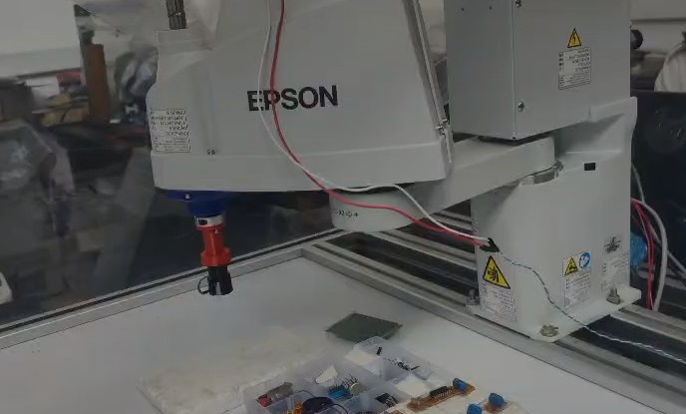
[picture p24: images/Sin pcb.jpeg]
Ver video de Simulación
    
  </a>
</p>

<p align="center">
  <b>
    Video de implentación Final fisica 1 (Prueba con pcb deja cristales sin coger por error de posición , velocidad X2)
      
  </b><br>
</p>

<p align="center">
  <a href="https://drive.google.com/file/d/11vFDaBi6A9irszO2-w8bLBX5rrz4HlgN/view?usp=drive_link">
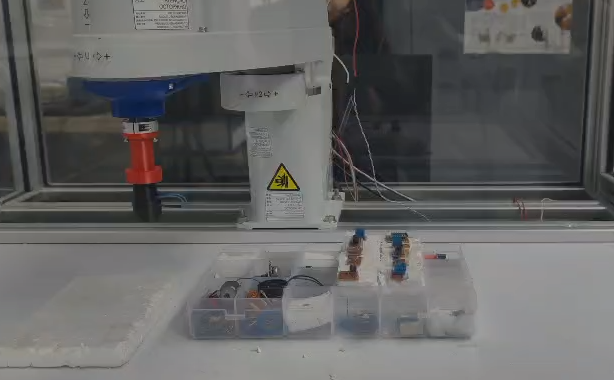
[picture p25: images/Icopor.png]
Ver video en Drive
    
  </a>
</p>

<p align="center">
  <b>
    Video de implentación Final fisica 1 (Prueba con pcb deja 3 ultimos componentes sin coger por sobrecalientamiento del electroiman y perdidas de sus propiedades , velocidad X2)
      
  </b><br>
</p>

<p align="center">
  <a href=https://drive.google.com/file/d/12U9qxxCNTWIHBtag4S1UQ17y6P2RlNQ5/view?usp=drive_link">
    Ver video en Drive
  </a>
</p>

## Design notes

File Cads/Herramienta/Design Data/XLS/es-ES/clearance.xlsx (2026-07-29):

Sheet: Roscas unificadas ANSI
I | Establecer orden -1
Tipo de fiador | Tamaño | Diámetros del eje |  |  | Cotas de la cabeza
 |  | Cerrar | Normal | Holgado | Diámetro | Profundidad/ángulo | Tipo de cabeza
Tornillo para maquinaria de cabeza plana (82) | #0 | 0.0635 | 0.07 | 0.073 | 0.119 | 82 | 2
Tornillo para maquinaria de cabeza plana (82) | #1 | 0.076 | 0.081 | 0.089 | 0.146 | 82 | 2
Tornillo para maquinaria de cabeza plana (82) | #2 | 0.089 | 0.096 | 0.1065 | 0.172 | 82 | 2
Tornillo para maquinaria de cabeza plana (82) | #3 | 0.104 | 0.11 | 0.12 | 0.199 | 82 | 2
Tornillo para maquinaria de cabeza plana (82) | #4 | 0.116 | 0.1285 | 0.136 | 0.225 | 82 | 2
Tornillo para maquinaria de cabeza plana (82) | #5 | 0.1285 | 0.136 | 0.154 | 0.252 | 82 | 2
Tornillo para maquinaria de cabeza plana (82) | #6 | 0.144 | 0.1495 | 0.1695 | 0.279 | 82 | 2
Tornillo para maquinaria de cabeza plana (82) | #8 | 0.1695 | 0.177 | 0.1935 | 0.332 | 82 | 2
Tornillo para maquinaria de cabeza plana (82) | #10 | 0.196 | 0.201 | 0.221 | 0.385 | 82 | 2
Tornillo para maquinaria de cabeza plana (82) | #12 | 0.221 | 0.228 | 0.246 | 0.438 | 82 | 2
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

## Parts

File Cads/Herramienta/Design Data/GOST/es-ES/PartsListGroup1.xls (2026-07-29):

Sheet: Лист 1
Инв. № подл |  |  |  | Подп. и дата | Взам. инв. № | Инв. № дубл. |  |  | Подп. и дата
Формат | Зона | Поз. | Обозначение |  |  |  | Наименование |  |  |  |  |  | Кол. на исполнение
 |  |  |  |  |  |  |  |  |  |  |  | Лит.
 |  |  |  |  |  |  |  |  |  |  |  | Код
 |  |  |  |  |  |  |  | Изм. | Лист | № докум | Подпись |  | Дата
 |  |  |  |  |  |  |  | Разраб.
 |  |  |  |  |  |  |  | Пров.
 |  |  |  |  |  |  |  | Н.контр
 |  |  |  |  |  |  |  | Утв.
 |  |  |  |  |  |  |  |  |  |  |  |  |  | Копировал

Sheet: Лист 2
Инв. № подл |  |  |  | Подп. и дата | Взам. инв. № | Инв. № дубл. |  |  | Подп. и дата
Формат | Зона | Поз. | Обозначение |  |  |  | Наименование |  |  |  |  | Кол. на исполнение
 |  |  |  |  |  |  |  | Изм. | Лист | № докум. | Подп. | Дата
 |  |  |  |  |  |  |  |  |  |  |  |  | Копировал
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

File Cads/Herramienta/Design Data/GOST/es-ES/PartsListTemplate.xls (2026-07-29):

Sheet: Лист 1
 | Формат | Зона |  | Поз. |  | Обозначение |  |  |  | Наименование |  |  |  | Кол. | Приме-чание
Подп. и дата
Инв. № дубл.
Взам. инв. №
Подп. и дата
 | Изм. |  | Лист |  | № докум |  | Подпись | Дата
Инв. № подл | Разраб. |  |  |  |  |  |  |  |  |  | Литера |  | Лист |  |  | Листов
 | Пров.
 | Н.контр
 | Утв.
 |  |  |  |  |  |  |  |  | Копировал |  |  | Формат А4

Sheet: Лист 2
 | Формат | Зона |  | Поз. |  | Обозначение |  |  |  | Наименование |  | Кол. | Приме-чание
Подп. и дата
Инв. № дубл.
Взам. инв. №
Подп. и дата
Инв. № подл
 | Изм. |  | Лист |  | № докум. |  | Подп. |  | Дата
 |  |  |  |  |  |  |  | Копировал |  |  | Формат А4
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

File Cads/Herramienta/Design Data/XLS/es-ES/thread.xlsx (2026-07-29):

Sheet: Inch Tapping Threads
I Q X | Roscas macho en pulgadas |  | Sort Order - 5 |  | External |  |  |  |  |  |  | Internal
 |  |  |  |  |  | Major Dia |  | Pitch Dia |  | Minor Dia |  |  | Minor Dia |  | Pitch Dia |  | Major Dia |  | Tap Drill
Size | Size Suffix | Thread Designation | Custom Thread Designation | TPI | Class | Max | Min | Max | Min | Max | Min | Class | Min | Max | Min | Max | Min | Max | Basic
0.0600 |  | 0-48 | 0-48 | 48 | 2B | 0.0600 | 0.0540 | 0.0480 | 0.0435 | 0.0360 | 0.0330
0.0730 |  | 1-42 | 1-42 | 42 | 2B | 0.0750 | 0.0690 | 0.0620 | 0.0575 | 0.0490 | 0.0460
0.0860 |  | 2-32 | 2-32 | 32 | 2B | 0.0880 | 0.0820 | 0.0760 | 0.0710 | 0.0640 | 0.0600
0.0990 |  | 3-28 | 3-28 | 28 | 2B | 0.1010 | 0.0950 | 0.0880 | 0.0830 | 0.0750 | 0.0710
0.1120 |  | 4-24 | 4-24 | 24 | 2B | 0.1140 | 0.1080 | 0.1000 | 0.0950 | 0.0860 | 0.0820
0.1250 |  | 5-20 | 5-20 | 20 | 2B | 0.1300 | 0.1230 | 0.1120 | 0.1065 | 0.0940 | 0.0900
0.1380 |  | 6-20 | 6-20 | 20 | 2B | 0.1390 | 0.1320 | 0.1215 | 0.1155 | 0.1040 | 0.0990
0.1510 |  | 7-19 | 7-19 | 19 | 2B | 0.1540 | 0.1470 | 0.1345 | 0.1280 | 0.1150 | 0.1090
0.1640 |  | 8-18 | 8-18 | 18 | 2B | 0.1660 | 0.1590 | 0.1440 | 0.1375 | 0.1220 | 0.1160
0.1900 |  | 10-16 | 10-16 | 16 | 2B | 0.1890 | 0.1820 | 0.1650 | 0.1585 | 0.1410 | 0.1350
0.2160 |  | 12-14 | 12-14 | 14 | 2B | 0.2150 | 0.2080 | 0.1895 | 0.1825 | 0.1640 | 0.1570
0.2420 |  | 14-14 | 14-14 | 14 | 2B | 0.2410 | 0.2340 | 0.2130 | 0.2060 | 0.1850 | 0.1780
0.2500 |  | 1/4-14 | 1/4-14 | 14 | 2B | 0.2460 | 0.2370 | 0.2190 | 0.2110 | 0.1920 | 0.1850
0.3125 |  | 5/16-12 | 5/16-12 | 12 | 2B | 0.3150 | 0.3060 | 0.2795 | 0.2710 | 0.2440 | 0.2360
0.3750 |  | 3/8-12 | 3/8-12 | 12 | 2B | 0.3800 | 0.3710 | 0.3445 | 0.3350 | 0.3090 | 0.2990
0.4375 |  | 7/16-10 | 7/16-10 | 10 | 2B | 0.4400 | 0.4290 | 0.3995 | 0.3890 | 0.3590 | 0.3490
0.5000 |  | 1/2-10 | 1/2-10 | 10 | 2B | 0.5040 | 0.4930 | 0.4635 | 0.4530 | 0.4230 | 0.4130

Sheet: Metric Forming Screw Threads
M P X | Roscas de tornillo métricas |  | Sort Order - 6 |  | External |  |  |  |  |  |  | Internal
 |  |  |  |  |  | Major Dia |  | Pitch Dia |  | Minor Dia |  |  | Minor Dia |  | Pitch Dia |  | Major Dia |  | Tap Drill
Size | Size Suffix | Thread Designation | Custom Thread Designation | Pitch | Class | Max | Min | Max | Min | Max | Min | Class | Min | Max | Min | Max | Min | Max | Basic
1.5 |  | 1.5x0.5 | 1.5x0.5 | 0.5 | 6g | 1.520 | 1.380 | 1.215 | 1.110 | 0.910 | 0.840
1.5 |  | ST1.5x0.5 | ST1.5x0.5 | 0.5 | 6g | 1.520 | 1.380 | 1.215 | 1.110 | 0.910 | 0.840
1.9 |  | 1.9x0.6 | 1.9x0.6 | 0.6 | 6g | 1.900 | 1.760 | 1.570 | 1.465 | 1.240 | 1.170
1.9 |  | ST1.9x0.6 | ST1.9x0.6 | 0.6 | 6g | 1.900 | 1.760 | 1.570 | 1.465 | 1.240 | 1.170
2.2 |  | 2.2x0.8 | 2.2x0.8 | 0.8 | 6g | 2.240 | 2.100 | 1.935 | 1.810 | 1.630 | 1.520
2.2 |  | ST2.2x0.8 | ST2.2x0.8 | 0.8 | 6g | 2.240 | 2.100 | 1.935 | 1.810 | 1.630 | 1.520
2.6 |  | 2.6x0.9 | 2.6x0.9 | 0.9 | 6g | 2.570 | 2.430 | 2.235 | 2.115 | 1.900 | 1.800
2.6 |  | ST2.6x0.9 | ST2.6x0.9 | 0.9 | 6g | 2.570 | 2.430 | 2.235 | 2.115 | 1.900 | 1.800
2.9 |  | 2.9x1 | 2.9x1 | 1 | 6g | 2.900 | 2.760 | 2.540 | 2.420 | 2.180 | 2.080
2.9 |  | 2.9x1.1 | 2.9x1.1 | 1.1 | 6g | 2.900 | 2.760 | 2.540 | 2.420 | 2.180 | 2.080
2.9 |  | ST2.9x1.1 | ST2.9x1.1 | 1.1 | 6g | 2.900 | 2.760 | 2.540 | 2.420 | 2.180 | 2.080
2.9 |  | 2.9x1.3 | 2.9x1.3 | 1.3 | 6g | 2.900 | 2.720 | 2.540 | 2.355 | 1.890 | 1.700
2.9 |  | 2.9x1.4 | 2.9x1.4 | 1.4 | 6g | 2.900 | 2.720 | 2.340 | 2.175 | 1.780 | 1.630
3.3 |  | 3.3x1.3 | 3.3x1.3 | 1.3 | 6g | 3.300 | 3.120 | 2.795 | 2.665 | 2.290 | 2.210
3.3 |  | ST3.3x1.3 | ST3.3x1.3 | 1.3 | 6g | 3.300 | 3.120 | 2.795 | 2.665 | 2.290 | 2.210
3.5 |  | 3.5x1.3 | 3.5x1.3 | 1.3 | 6g | 3.530 | 3.350 | 3.085 | 2.930 | 2.640 | 2.510
3.5 |  | ST3.5x1.3 | ST3.5x1.3 | 1.3 | 6g | 3.530 | 3.350 | 3.085 | 2.930 | 2.640 | 2.510
3.5 |  | 3.5x1.6 | 3.5x1.6 | 1.6 | 6g | 3.530 | 3.350 | 2.920 | 2.755 | 2.310 | 2.160
3.5 |  | 3.5x3.2 | 3.5x3.2 | 3.2 | 6g | 3.530 | 3.310 | 2.800 | 2.600 | 2.070 | 1.890
3.9 |  | 3.9x1.3 | 3.9x1.3 | 1.3 | 6g | 3.910 | 3.730 | 3.415 | 3.250 | 2.920 | 2.770
3.9 |  | ST3.9x1.3 | ST3.9x1.3 | 1.3 | 6g | 3.910 | 3.730 | 3.415 | 3.250 | 2.920 | 2.770
3.9 |  | 3.9x1.6 | 3.9x1.6 | 1.6 | 6g | 3.910 | 3.730 | 3.300 | 3.135 | 2.690 | 2.540
3.9 |  | 3.9x3.2 | 3.9x3.2 | 3.2 | 6g | 3.910 | 3.690 | 3.180 | 2.980 | 2.450 | 2.270
4.2 |  | 4.2x1.4 | 4.2x1.4 | 1.4 | 6g | 4.220 | 4.040 | 3.660 | 3.495 | 3.100 | 2.950
4.2 |  | ST4.2x1.4 | ST4.2x1.4 | 1.4 | 6g | 4.220 | 4.040 | 3.660 | 3.495 | 3.100 | 2.950
4.2 |  | 4.2x1.6 | 4.2x1.6 | 1.6 | 6g | 4.220 | 4.040 | 3.610 | 3.445 | 3.000 | 2.850
4.2 |  | 4.2x3.2 | 4.2x3.2 | 3.2 | 6g | 4.220 | 4.000 | 3.380 | 3.180 | 2.540 | 2.360
4.8 |  | 4.8x1.6 | 4.8x1.6 | 1.6 | 6g | 4.800 | 4.620 | 4.190 | 4.025 | 3.580 | 3.430
4.8 |  | ST4.8x1.6 | ST4.8x1.6 | 1.6 | 6g | 4.800 | 4.620 | 4.190 | 4.025 | 3.580 | 3.430
4.8 |  | 4.8x1.8 | 4.8x1.8 | 1.8 | 6g | 4.800 | 4.620 | 4.065 | 3.885 | 3.330 | 3.150
4.8 |  | 4.8x3.2 | 4.8x3.2 | 3.2 | 6g | 4.800 | 4.580 | 3.960 | 3.760 | 3.120 | 2.940
5.5 |  | 5.5x1.8 | 5.5x1.8 | 1.8 | 6g | 5.460 | 5.280 | 4.815 | 4.635 | 4.170 | 3.990
5.5 |  | ST5.5x1.8 | ST5.5x1.8 | 1.8 | 6g | 5.460 | 5.280 | 4.815 | 4.635 | 4.170 | 3.990
6.3 |  | 6.3x1.8 | 6.3x1.8 | 1.8 | 6g | 6.250 | 6.030 | 5.565 | 5.365 | 4.880 | 4.700
6.3 |  | ST6.3x1.8 | ST6.3x1.8 | 1.8 | 6g | 6.250 | 6.030 | 5.565 | 5.365 | 4.880 | 4.700
8.0 |  | 8x2.1 | 8x2.1 | 2.1 | 6g | 8.000 | 7.780 | 7.100 | 6.885 | 6.200 | 5.990
8.0 |  | ST8x2.1 | ST8x2.1 | 2.1 | 6g | 8.000 | 7.780 | 7.100 | 6.885 | 6.200 | 5.990
9.5 |  | 9.5x2.1 | 9.5x2.1 | 2.1 | 6g | 9.650 | 9.430 | 8.750 | 8.510 | 7.850 | 7.590
9.5 |  | ST9.5x2.1 | ST9.5x2.1 | 2.1 | 6g | 9.650 | 9.430 | 8.750 | 8.510 | 7.850 | 7.590

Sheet: ISO Pipe Threads
M Q | Roscas de tubo ISO |  | Sort Order - 9 |  | External |  |  |  |  |  |  | Internal
 |  |  |  |  |  | Major Dia |  | Pitch Dia |  | Minor Dia |  |  | Minor Dia |  | Pitch Dia |  | Major Dia |  | Tap Drill | Thread Depth | Thread Runouts
Size | Size Suffix | Thread Designation | Custom Thread Designation | TPI | Class | Max | Min | Max | Min | Max | Min | Class | Min | Max | Min | Max | Min | Max | Basic
7.723 |  | G7.723x0.907 | G 1/16 | 28 | A | 7.723 | 7.509 | 7.142 | 7.035 | 6.561 |  |  | 6.561 | 6.834 | 7.142 | 7.249 | 7.723 |  | 1.5875 | 15.446 | 4.5000
7.723 |  | G7.723x0.907 | G 1/16 | 28 | B | 7.723 | 7.509 | 7.142 | 6.928 | 6.561
9.728 |  | G9.728x0.907 | G 1/8 | 28 | A | 9.728 | 9.514 | 9.147 | 9.040 | 8.566 |  |  | 8.566 | 8.848 | 9.147 | 9.254 | 9.728 |  | 3.1750 | 19.456 | 4.5000
9.728 |  | G9.728x0.907 | G 1/8 | 28 | B | 9.728 | 9.514 | 9.147 | 8.933 | 8.566
13.157 |  | G13.157x1.337 | G 1/4 | 19 | A | 13.157 | 12.907 | 12.301 | 12.176 | 11.445 |  |  | 11.445 | 11.89 | 12.301 | 12.426 | 13.157 |  | 6.3500 | 26.314 | 6.5000
13.157 |  | G13.157x1.337 | G 1/4 | 19 | B | 13.157 | 12.907 | 12.301 | 12.051 | 11.445
16.662 |  | G16.662x1.337 | G 3/8 | 19 | A | 16.662 | 16.412 | 15.806 | 15.681 | 14.950 |  |  | 14.95 | 15.395 | 15.806 | 15.931 | 16.662 |  | 9.5250 | 33.324 | 6.5000
16.662 |  | G16.662x1.337 | G 3/8 | 19 | B | 16.662 | 16.412 | 15.806 | 15.556 | 14.950
20.955 |  | G20.955x1.814 | G 1/2 | 14 | A | 20.955 | 20.671 | 19.793 | 19.651 | 18.631 |  |  | 18.631 | 19.172 | 19.793 | 19.935 | 20.955 |  | 12.7000 | 41.910 | 8.5000
20.955 |  | G20.955x1.814 | G 1/2 | 14 | B | 20.955 | 20.671 | 19.793 | 19.509 | 18.631
22.911 |  | G22.911x1.814 | G 5/8 | 14 | A | 22.911 | 22.627 | 21.749 | 21.607 | 20.587 |  |  | 20.587 | 21.128 | 21.749 | 21.891 | 22.911 |  |  | 45.822 | 8.5000
22.911 |  | G22.911x1.814 | G 5/8 | 14 | B | 22.911 | 22.627 | 21.749 | 21.465 | 20.587
26.441 |  | G26.441x1.814 | G 3/4 | 14 | A | 26.441 | 26.157 | 25.279 | 25.137 | 24.117 |  |  | 24.117 | 24.658 | 25.279 | 25.421 | 26.441 |  | 15.8750 | 52.882 | 8.5000
26.441 |  | G26.441x1.814 | G 3/4 | 14 | B | 26.441 | 26.157 | 25.279 | 24.995 | 24.117
30.201 |  | G30.201x1.814 | G 7/8 | 14 | A | 30.201 | 29.917 | 29.039 | 28.897 | 27.877 |  |  | 27.877 | 28.418 | 29.039 | 29.181 | 30.201 |  | 22.2250 | 60.402 | 8.5000
30.201 |  | G30.201x1.814 | G 7/8 | 14 | B | 30.201 | 29.917 | 29.039 | 28.755 | 27.877
33.249 |  | G33.249x2.309 | G 1 | 11 | A | 33.249 | 32.889 | 31.770 | 31.590 | 30.291 |  |  | 30.291 | 30.931 | 31.77 | 31.95 | 33.249 |  | 25.4000 | 66.498 | 10.0000
33.249 |  | G33.249x2.309 | G 1 | 11 | B | 33.249 | 32.889 | 31.770 | 31.410 | 30.291
37.897 |  | G37.897x2.309 | G 1 1/8 | 11 | A | 37.897 | 37.537 | 36.418 | 36.238 | 34.939 |  |  | 34.939 | 35.579 | 36.418 | 36.598 | 37.897 |  | 28.5750 | 75.794 | 10.0000
37.897 |  | G37.897x2.309 | G 1 1/8 | 11 | B | 37.897 | 37.537 | 36.418 | 36.058 | 34.939
41.910 |  | G41.91x2.309 | G 1 1/4 | 11 | A | 41.910 | 41.550 | 40.431 | 40.251 | 38.952 |  |  | 38.952 | 39.592 | 40.431 | 40.611 | 41.910 |  | 31.7500 | 83.820 | 10.0000
41.910 |  | G41.91x2.309 | G 1 1/4 | 11 | B | 41.910 | 41.550 | 40.431 | 40.071 | 38.952
47.803 |  | G47.803x2.309 | G 1 1/2 | 11 | A | 47.803 | 47.443 | 46.324 | 46.144 | 44.845 |  |  | 44.845 | 45.485 | 46.324 | 46.504 | 47.803 |  | 38.1000 | 95.606 | 10.0000
47.803 |  | G47.803x2.309 | G 1 1/2 | 11 | B | 47.803 | 47.443 | 46.324 | 45.964 | 44.845
53.746 |  | G53.746x2.309 | G 1 3/4 | 11 | A | 53.746 | 53.386 | 52.267 | 52.087 | 50.788 |  |  | 50.788 | 51.428 | 52.267 | 52.447 | 53.746 |  | 44.4500 | 107.492 | 10.0000
53.746 |  | G53.746x2.309 | G 1 3/4 | 11 | B | 53.746 | 53.386 | 52.267 | 51.907 | 50.788
59.614 |  | G59.614x2.309 | G 2 | 11 | A | 59.614 | 59.254 | 58.135 | 57.955 | 56.656 |  |  | 56.656 | 57.296 | 58.135 | 58.315 | 59.614 |  | 50.8000 | 119.228 | 10.0000
59.614 |  | G59.614x2.309 | G 2 | 11 | B | 59.614 | 59.254 | 58.135 | 57.775 | 56.656
65.710 |  | G65.71x2.309 | G 2 1/4 | 11 | A | 65.710 | 65.276 | 64.231 | 64.014 | 62.752 |  |  | 62.752 | 63.392 | 64.231 | 64.448 | 65.710 |  | 57.1500 | 131.420 | 10.0000
65.710 |  | G65.71x2.309 | G 2 1/4 | 11 | B | 65.710 | 65.276 | 64.231 | 63.797 | 62.752
75.184 |  | G75.184x2.309 | G 2 1/2 | 11 | A | 75.184 | 74.750 | 73.705 | 73.488 | 72.226 |  |  | 72.226 | 72.866 | 73.705 | 73.922 | 75.184 |  |  | 150.368 | 10.0000
75.184 |  | G75.184x2.309 | G 2 1/2 | 11 | B | 75.184 | 74.750 | 73.705 | 73.271 | 72.226
81.534 |  | G81.534x2.309 | G 2 3/4 | 11 | A | 81.534 | 81.100 | 80.055 | 79.838 | 78.576 |  |  | 78.576 | 79.216 | 80.055 | 80.272 | 81.534 |  | 69.8500 | 163.068 | 10.0000
81.534 |  | G81.534x2.309 | G 2 3/4 | 11 | B | 81.534 | 81.100 | 80.055 | 79.621 | 78.576
87.884 |  | G87.884x2.309 | G 3 | 11 | A | 87.884 | 87.450 | 86.405 | 86.188 | 84.926 |  |  | 84.926 | 85.566 | 86.405 | 86.622 | 87.884 |  | 76.2000 | 175.768 | 10.0000
87.884 |  | G87.884x2.309 | G 3 | 11 | B | 87.884 | 87.450 | 86.405 | 85.971 | 84.926
100.330 |  | G100.33x2.309 | G 3 1/2 | 11 | A | 100.330 | 99.896 | 98.851 | 98.634 | 97.372 |  |  | 97.372 | 98.012 | 98.851 | 99.068 | 100.330 |  | 88.9000 | 200.660 | 10.0000
100.330 |  | G100.33x2.309 | G 3 1/2 | 11 | B | 100.330 | 99.896 | 98.851 | 98.417 | 97.372
113.030 |  | G113.03x2.309 | G 4 | 11 | A | 113.030 | 112.596 | 111.551 | 111.334 | 110.072 |  |  | 110.072 | 110.712 | 111.551 | 111.768 | 113.030 |  | 101.6000 | 226.060 | 10.0000
113.030 |  | G113.03x2.309 | G 4 | 11 | B | 113.030 | 112.596 | 111.551 | 111.117 | 110.072
125.730 |  | G125.73x2.309 | G 4 1/2 | 11 | A | 125.730 | 125.296 | 124.251 | 124.034 | 122.772 |  |  | 122.772 | 123.412 | 124.251 | 124.468 | 125.730 |  | 114.3000 | 251.460 | 10.0000
125.730 |  | G125.73x2.309 | G 4 1/2 | 11 | B | 125.730 | 125.296 | 124.251 | 123.817 | 122.772
138.430 |  | G138.43x2.309 | G 5 | 11 | A | 138.430 | 137.996 | 136.951 | 136.734 | 135.472 |  |  | 135.472 | 136.112 | 136.951 | 137.168 | 138.430 |  | 127.0000 | 276.860 | 10.0000
138.430 |  | G138.43x2.309 | G 5 | 11 | B | 138.430 | 137.996 | 136.951 | 136.517 | 135.472
151.130 |  | G151.13x2.309 | G 5 1/2 | 11 | A | 151.130 | 150.696 | 149.651 | 149.434 | 148.172 |  |  | 148.172 | 148.812 | 149.651 | 149.868 | 151.130 |  | 139.7000 | 302.260 | 10.0000
151.130 |  | G151.13x2.309 | G 5 1/2 | 11 | B | 151.130 | 150.696 | 149.651 | 149.217 | 148.172
163.830 |  | G163.83x2.309 | G 6 | 11 | A | 163.830 | 163.396 | 162.351 | 162.134 | 160.872 |  |  | 160.872 | 161.512 | 162.351 | 162.568 | 163.830 |  | 152.4000 | 327.660 | 10.0000
163.830 |  | G163.83x2.309 | G 6 | 11 | B | 163.830 | 163.396 | 162.351 | 161.917 | 160.872

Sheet: JIS Pipe Threads
M Q | Roscas de tubo JIS |  | Sort Order -12 |  | External |  |  |  |  |  |  | Internal
 |  |  |  |  |  | Major Dia |  | Pitch Dia |  | Minor Dia |  |  | Minor Dia |  | Pitch Dia |  | Major Dia |  | Tap Drill | Thread Depth | Thread Runouts
Size | Size Suffix | Thread Designation | Custom Thread Designation | TPI | Class | Max | Min | Max | Min | Max | Min | Class | Min | Max | Min | Max | Min | Max | Basic |  | Basic
7.723 |  | G7.723x0.907 | G 1/16 | 28 | A | 7.723 | 7.509 | 7.142 | 7.035 | 6.561 |  |  | 6.561 | 6.834 | 7.142 | 7.249 | 7.723 |  | 1.5875 | 15.446 | 4.5000
7.723 |  | G7.723x0.907 | G 1/16 | 28 | B | 7.723 | 7.509 | 7.142 | 6.928 | 6.561
9.728 |  | G9.728x0.907 | G 1/8 | 28 | A | 9.728 | 9.514 | 9.147 | 9.040 | 8.566 |  |  | 8.566 | 8.848 | 9.147 | 9.254 | 9.728 |  | 3.1750 | 19.456 | 4.5000
9.728 |  | G9.728x0.907 | G 1/8 | 28 | B | 9.728 | 9.514 | 9.147 | 8.933 | 8.566
13.157 |  | G13.157x1.337 | G 1/4 | 19 | A | 13.157 | 12.907 | 12.301 | 12.176 | 11.445 |  |  | 11.445 | 11.89 | 12.301 | 12.426 | 13.157 |  | 6.3500 | 26.314 | 6.5000
13.157 |  | G13.157x1.337 | G 1/4 | 19 | B | 13.157 | 12.907 | 12.301 | 12.051 | 11.445
16.662 |  | G16.662x1.337 | G 3/8 | 19 | A | 16.662 | 16.412 | 15.806 | 15.681 | 14.950 |  |  | 14.95 | 15.395 | 15.806 | 15.931 | 16.662 |  | 9.5250 | 33.324 | 6.5000
16.662 |  | G16.662x1.337 | G 3/8 | 19 | B | 16.662 | 16.412 | 15.806 | 15.556 | 14.950
20.955 |  | G20.955x1.814 | G 1/2 | 14 | A | 20.955 | 20.671 | 19.793 | 19.651 | 18.631 |  |  | 18.631 | 19.172 | 19.793 | 19.935 | 20.955 |  | 12.7000 | 41.910 | 8.5000
20.955 |  | G20.955x1.814 | G 1/2 | 14 | B | 20.955 | 20.671 | 19.793 | 19.509 | 18.631
22.911 |  | G22.911x1.814 | G 5/8 | 14 | A | 22.911 | 22.627 | 21.749 | 21.607 | 20.587 |  |  | 20.587 | 21.128 | 21.749 | 21.891 | 22.911 |  |  | 45.822 | 8.5000
22.911 |  | G22.911x1.814 | G 5/8 | 14 | B | 22.911 | 22.627 | 21.749 | 21.465 | 20.587
26.441 |  | G26.441x1.814 | G 3/4 | 14 | A | 26.441 | 26.157 | 25.279 | 25.137 | 24.117 |  |  | 24.117 | 24.658 | 25.279 | 25.421 | 26.441 |  | 15.8750 | 52.882 | 8.5000
26.441 |  | G26.441x1.814 | G 3/4 | 14 | B | 26.441 | 26.157 | 25.279 | 24.995 | 24.117
30.201 |  | G30.201x1.814 | G 7/8 | 14 | A | 30.201 | 29.917 | 29.039 | 28.897 | 27.877 |  |  | 27.877 | 28.418 | 29.039 | 29.181 | 30.201 |  | 22.2250 | 60.402 | 8.8000
30.201 |  | G30.201x1.814 | G 7/8 | 14 | B | 30.201 | 29.917 | 29.039 | 28.755 | 27.877
33.249 |  | G33.249x2.309 | G 1 | 11 | A | 33.249 | 32.889 | 31.770 | 31.590 | 30.291 |  |  | 30.291 | 30.931 | 31.77 | 31.95 | 33.249 |  | 25.4000 | 66.498 | 10.0000
33.249 |  | G33.249x2.309 | G 1 | 11 | B | 33.249 | 32.889 | 31.770 | 31.410 | 30.291
37.897 |  | G37.897x2.309 | G 1 1/8 | 11 | A | 37.897 | 37.537 | 36.418 | 36.238 | 34.939 |  |  | 34.939 | 35.579 | 36.418 | 36.598 | 37.897 |  | 28.5750 | 75.794 | 10.0000
37.897 |  | G37.897x2.309 | G 1 1/8 | 11 | B | 37.897 | 37.537 | 36.418 | 36.058 | 34.939
41.910 |  | G41.91x2.309 | G 1 1/4 | 11 | A | 41.910 | 41.550 | 40.431 | 40.251 | 38.952 |  |  | 38.952 | 39.592 | 40.431 | 40.611 | 41.910 |  | 31.7500 | 83.820 | 10.0000
41.910 |  | G41.91x2.309 | G 1 1/4 | 11 | B | 41.910 | 41.550 | 40.431 | 40.071 | 38.952
47.803 |  | G47.803x2.309 | G 1 1/2 | 11 | A | 47.803 | 47.443 | 46.324 | 46.144 | 44.845 |  |  | 44.845 | 45.485 | 46.324 | 46.504 | 47.803 |  | 38.1000 | 95.606 | 10.0000
47.803 |  | G47.803x2.309 | G 1 1/2 | 11 | B | 47.803 | 47.443 | 46.324 | 45.964 | 44.845
53.746 |  | G53.746x2.309 | G 1 3/4 | 11 | A | 53.746 | 53.386 | 52.267 | 52.087 | 50.788 |  |  | 50.788 | 51.428 | 52.267 | 52.447 | 53.746 |  | 44.4500 | 107.492 | 10.0000
53.746 |  | G53.746x2.309 | G 1 3/4 | 11 | B | 53.746 | 53.386 | 52.267 | 51.907 | 50.788
59.614 |  | G59.614x2.309 | G 2 | 11 | A | 59.614 | 59.254 | 58.135 | 57.955 | 56.656 |  |  | 56.656 | 57.296 | 58.135 | 58.315 | 59.614 |  | 50.8000 | 119.228 | 10.0000
59.614 |  | G59.614x2.309 | G 2 | 11 | B | 59.614 | 59.254 | 58.135 | 57.775 | 56.656
65.710 |  | G65.71x2.309 | G 2 1/4 | 11 | A | 65.710 | 65.276 | 64.231 | 64.014 | 62.752 |  |  | 62.752 | 63.392 | 64.231 | 64.448 | 65.710 |  | 57.1500 | 131.420 | 10.0000
65.710 |  | G65.71x2.309 | G 2 1/4 | 11 | B | 65.710 | 65.276 | 64.231 | 63.797 | 62.752
75.184 |  | G75.184x2.309 | G 2 1/2 | 11 | A | 75.184 | 74.750 | 73.705 | 73.488 | 72.226 |  |  | 72.226 | 72.866 | 73.705 | 73.922 | 75.184 |  |  | 150.368 | 10.0000
75.184 |  | G75.184x2.309 | G 2 1/2 | 11 | B | 75.184 | 74.750 | 73.705 | 73.271 | 72.226
81.534 |  | G81.534x2.309 | G 2 3/4 | 11 | A | 81.534 | 81.100 | 80.055 | 79.838 | 78.576 |  |  | 78.576 | 79.216 | 80.055 | 80.272 | 81.534 |  | 69.8500 | 163.068 | 10.0000
81.534 |  | G81.534x2.309 | G 2 3/4 | 11 | B | 81.534 | 81.100 | 80.055 | 79.621 | 78.576
87.884 |  | G87.884x2.309 | G 3 | 11 | A | 87.884 | 87.450 | 86.405 | 86.188 | 84.926 |  |  | 84.926 | 85.566 | 86.405 | 86.622 | 87.884 |  | 76.2000 | 175.768 | 10.0000
87.884 |  | G87.884x2.309 | G 3 | 11 | B | 87.884 | 87.450 | 86.405 | 85.971 | 84.926
100.330 |  | G100.33x2.309 | G 3 1/2 | 11 | A | 100.330 | 99.896 | 98.851 | 98.634 | 97.372 |  |  | 97.372 | 98.012 | 98.851 | 99.068 | 100.330 |  | 88.9000 | 200.660 | 10.0000
100.330 |  | G100.33x2.309 | G 3 1/2 | 11 | B | 100.330 | 99.896 | 98.851 | 98.417 | 97.372
113.030 |  | G113.03x2.309 | G 4 | 11 | A | 113.030 | 112.596 | 111.551 | 111.334 | 110.072 |  |  | 110.072 | 110.712 | 111.551 | 111.768 | 113.030 |  | 101.6000 | 226.060 | 10.0000
113.030 |  | G113.03x2.309 | G 4 | 11 | B | 113.030 | 112.596 | 111.551 | 111.117 | 110.072
125.730 |  | G125.73x2.309 | G 4 1/2 | 11 | A | 125.730 | 125.296 | 124.251 | 124.034 | 122.772 |  |  | 122.772 | 123.412 | 124.251 | 124.468 | 125.730 |  | 114.3000 | 251.460 | 10.0000
125.730 |  | G125.73x2.309 | G 4 1/2 | 11 | B | 125.730 | 125.296 | 124.251 | 123.817 | 122.772
138.430 |  | G138.43x2.309 | G 5 | 11 | A | 138.430 | 137.996 | 136.951 | 136.734 | 135.472 |  |  | 135.472 | 136.112 | 136.951 | 137.168 | 138.430 |  | 127.0000 | 276.860 | 10.0000
138.430 |  | G138.43x2.309 | G 5 | 11 | B | 138.430 | 137.996 | 136.951 | 136.517 | 135.472
151.130 |  | G151.13x2.309 | G 5 1/2 | 11 | A | 151.130 | 150.696 | 149.651 | 149.434 | 148.172 |  |  | 148.172 | 148.812 | 149.651 | 149.868 | 151.130 |  | 139.7000 | 302.260 | 10.0000
151.130 |  | G151.13x2.309 | G 5 1/2 | 11 | B | 151.130 | 150.696 | 149.651 | 149.217 | 148.172
163.830 |  | G163.83x2.309 | G 6 | 11 | A | 163.830 | 163.396 | 162.351 | 162.134 | 160.872 |  |  | 160.872 | 161.512 | 162.351 | 162.568 | 163.830 |  | 152.4000 | 327.660 | 10.0000
163.830 |  | G163.83x2.309 | G 6 | 11 | B | 163.830 | 163.396 | 162.351 | 161.917 | 160.872

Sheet: DIN Pipe Threads
M Q | Roscas de tubo DIN |  | Sort Order - 18 |  | External |  |  |  |  |  |  | Internal
 |  |  |  |  |  | Major Dia |  | Pitch Dia |  | Minor Dia |  |  | Minor Dia |  | Pitch Dia |  | Major Dia |  | Tap Drill | Thread Depth | Thread Runouts
Size | Size Suffix | Thread Designation | Custom Thread Designation | TPI | Class | Max | Min | Max | Min | Max | Min | Class | Min | Max | Min | Max | Min | Max | Basic
7.723 |  | G7.723x0.907 | G 1/16 | 28 | A | 7.723 | 7.509 | 7.142 | 7.035 | 6.561 |  |  | 6.561 | 6.834 | 7.142 | 7.249 | 7.723 |  | 1.5875 | 15.446 | 4.5000
7.723 |  | G7.723x0.907 | G 1/16 | 28 | B | 7.723 | 7.509 | 7.142 | 6.928 | 6.561
9.728 |  | G9.728x0.907 | G 1/8 | 28 | A | 9.728 | 9.514 | 9.147 | 9.040 | 8.566 |  |  | 8.566 | 8.848 | 9.147 | 9.254 | 9.728 |  | 3.1750 | 19.456 | 4.5000
9.728 |  | G9.728x0.907 | G 1/8 | 28 | B | 9.728 | 9.514 | 9.147 | 8.933 | 8.566
13.157 |  | G13.157x1.337 | G 1/4 | 19 | A | 13.157 | 12.907 | 12.301 | 12.176 | 11.445 |  |  | 11.445 | 11.89 | 12.301 | 12.426 | 13.157 |  | 6.3500 | 26.314 | 6.5000
13.157 |  | G13.157x1.337 | G 1/4 | 19 | B | 13.157 | 12.907 | 12.301 | 12.051 | 11.445
16.662 |  | G16.662x1.337 | G 3/8 | 19 | A | 16.662 | 16.412 | 15.806 | 15.681 | 14.950 |  |  | 14.95 | 15.395 | 15.806 | 15.931 | 16.662 |  | 9.5250 | 33.324 | 6.5000
16.662 |  | G16.662x1.337 | G 3/8 | 19 | B | 16.662 | 16.412 | 15.806 | 15.556 | 14.950
20.955 |  | G20.955x1.814 | G 1/2 | 14 | A | 20.955 | 20.671 | 19.793 | 19.651 | 18.631 |  |  | 18.631 | 19.172 | 19.793 | 19.935 | 20.955 |  | 12.7000 | 41.910 | 8.5000
20.955 |  | G20.955x1.814 | G 1/2 | 14 | B | 20.955 | 20.671 | 19.793 | 19.509 | 18.631
22.911 |  | G22.911x1.814 | G 5/8 | 14 | A | 22.911 | 22.627 | 21.749 | 21.607 | 20.587 |  |  | 20.587 | 21.128 | 21.749 | 21.891 | 22.911 |  |  | 45.822 | 8.5000
22.911 |  | G22.911x1.814 | G 5/8 | 14 | B | 22.911 | 22.627 | 21.749 | 21.465 | 20.587
26.441 |  | G26.441x1.814 | G 3/4 | 14 | A | 26.441 | 26.157 | 25.279 | 25.137 | 24.117 |  |  | 24.117 | 24.658 | 25.279 | 25.421 | 26.441 |  | 15.8750 | 52.882 | 8.5000
26.441 |  | G26.441x1.814 | G 3/4 | 14 | B | 26.441 | 26.157 | 25.279 | 24.995 | 24.117
30.201 |  | G30.201x1.814 | G 7/8 | 14 | A | 30.201 | 29.917 | 29.039 | 28.897 | 27.877 |  |  | 27.877 | 28.418 | 29.039 | 29.181 | 30.201 |  | 22.2250 | 60.402 | 8.5000
30.201 |  | G30.201x1.814 | G 7/8 | 14 | B | 30.201 | 29.917 | 29.039 | 28.755 | 27.877
33.249 |  | G33.249x2.309 | G 1 | 11 | A | 33.249 | 32.889 | 31.770 | 31.590 | 30.291 |  |  | 30.291 | 30.931 | 31.77 | 31.95 | 33.249 |  | 25.4000 | 66.498 | 10.5000
33.249 |  | G33.249x2.309 | G 1 | 11 | B | 33.249 | 32.889 | 31.770 | 31.410 | 30.291
37.897 |  | G37.897x2.309 | G 1 1/8 | 11 | A | 37.897 | 37.537 | 36.418 | 36.238 | 34.939 |  |  | 34.939 | 35.579 | 36.418 | 36.598 | 37.897 |  | 28.5750 | 75.794 | 10.5000
37.897 |  | G37.897x2.309 | G 1 1/8 | 11 | B | 37.897 | 37.537 | 36.418 | 36.058 | 34.939
41.910 |  | G41.91x2.309 | G 1 1/4 | 11 | A | 41.910 | 41.550 | 40.431 | 40.251 | 38.952 |  |  | 38.952 | 39.592 | 40.431 | 40.611 | 41.910 |  | 31.7500 | 83.820 | 10.5000
41.910 |  | G41.91x2.309 | G 1 1/4 | 11 | B | 41.910 | 41.550 | 40.431 | 40.071 | 38.952
47.803 |  | G47.803x2.309 | G 1 1/2 | 11 | A | 47.803 | 47.443 | 46.324 | 46.144 | 44.845 |  |  | 44.845 | 45.485 | 46.324 | 46.504 | 47.803 |  | 38.1000 | 95.606 | 10.5000
47.803 |  | G47.803x2.309 | G 1 1/2 | 11 | B | 47.803 | 47.443 | 46.324 | 45.964 | 44.845
53.746 |  | G53.746x2.309 | G 1 3/4 | 11 | A | 53.746 | 53.386 | 52.267 | 52.087 | 50.788 |  |  | 50.788 | 51.428 | 52.267 | 52.447 | 53.746 |  | 44.4500 | 107.492 | 10.5000
53.746 |  | G53.746x2.309 | G 1 3/4 | 11 | B | 53.746 | 53.386 | 52.267 | 51.907 | 50.788
59.614 |  | G59.614x2.309 | G 2 | 11 | A | 59.614 | 59.254 | 58.135 | 57.955 | 56.656 |  |  | 56.656 | 57.296 | 58.135 | 58.315 | 59.614 |  | 50.8000 | 119.228 | 10.5000
59.614 |  | G59.614x2.309 | G 2 | 11 | B | 59.614 | 59.254 | 58.135 | 57.775 | 56.656
65.710 |  | G65.71x2.309 | G 2 1/4 | 11 | A | 65.710 | 65.276 | 64.231 | 64.014 | 62.752 |  |  | 62.752 | 63.392 | 64.231 | 64.448 | 65.710 |  | 57.1500 | 131.420 | 10.5000
65.710 |  | G65.71x2.309 | G 2 1/4 | 11 | B | 65.710 | 65.276 | 64.231 | 63.797 | 62.752
75.184 |  | G75.184x2.309 | G 2 1/2 | 11 | A | 75.184 | 74.750 | 73.705 | 73.488 | 72.226 |  |  | 72.226 | 72.866 | 73.705 | 73.922 | 75.184 |  |  | 150.368 | 10.5000
75.184 |  | G75.184x2.309 | G 2 1/2 | 11 | B | 75.184 | 74.750 | 73.705 | 73.271 | 72.226
81.534 |  | G81.534x2.309 | G 2 3/4 | 11 | A | 81.534 | 81.100 | 80.055 | 79.838 | 78.576 |  |  | 78.576 | 79.216 | 80.055 | 80.272 | 81.534 |  | 69.8500 | 163.068 | 10.5000
81.534 |  | G81.534x2.309 | G 2 3/4 | 11 | B | 81.534 | 81.100 | 80.055 | 79.621 | 78.576
87.884 |  | G87.884x2.309 | G 3 | 11 | A | 87.884 | 87.450 | 86.405 | 86.188 | 84.926 |  |  | 84.926 | 85.566 | 86.405 | 86.622 | 87.884 |  | 76.2000 | 175.768 | 10.5000
87.884 |  | G87.884x2.309 | G 3 | 11 | B | 87.884 | 87.450 | 86.405 | 85.971 | 84.926
100.330 |  | G100.33x2.309 | G 3 1/2 | 11 | A | 100.330 | 99.896 | 98.851 | 98.634 | 97.372 |  |  | 97.372 | 98.012 | 98.851 | 99.068 | 100.330 |  | 88.9000 | 200.660 | 10.5000
100.330 |  | G100.33x2.309 | G 3 1/2 | 11 | B | 100.330 | 99.896 | 98.851 | 98.417 | 97.372
113.030 |  | G113.03x2.309 | G 4 | 11 | A | 113.030 | 112.596 | 111.551 | 111.334 | 110.072 |  |  | 110.072 | 110.712 | 111.551 | 111.768 | 113.030 |  | 101.6000 | 226.060 | 10.5000
113.030 |  | G113.03x2.309 | G 4 | 11 | B | 113.030 | 112.596 | 111.551 | 111.117 | 110.072
125.730 |  | G125.73x2.309 | G 4 1/2 | 11 | A | 125.730 | 125.296 | 124.251 | 124.034 | 122.772 |  |  | 122.772 | 123.412 | 124.251 | 124.468 | 125.730 |  | 114.3000 | 251.460 | 10.5000
125.730 |  | G125.73x2.309 | G 4 1/2 | 11 | B | 125.730 | 125.296 | 124.251 | 123.817 | 122.772
138.430 |  | G138.43x2.309 | G 5 | 11 | A | 138.430 | 137.996 | 136.951 | 136.734 | 135.472 |  |  | 135.472 | 136.112 | 136.951 | 137.168 | 138.430 |  | 127.0000 | 276.860 | 10.5000
138.430 |  | G138.43x2.309 | G 5 | 11 | B | 138.430 | 137.996 | 136.951 | 136.517 | 135.472
151.130 |  | G151.13x2.309 | G 5 1/2 | 11 | A | 151.130 | 150.696 | 149.651 | 149.434 | 148.172 |  |  | 148.172 | 148.812 | 149.651 | 149.868 | 151.130 |  | 139.7000 | 302.260 | 10.5000
151.130 |  | G151.13x2.309 | G 5 1/2 | 11 | B | 151.130 | 150.696 | 149.651 | 149.217 | 148.172
163.830 |  | G163.83x2.309 | G 6 | 11 | A | 163.830 | 163.396 | 162.351 | 162.134 | 160.872 |  |  | 160.872 | 161.512 | 162.351 | 162.568 | 163.830 |  | 152.4000 | 327.660 | 10.5000
163.830 |  | G163.83x2.309 | G 6 | 11 | B | 163.830 | 163.396 | 162.351 | 161.917 | 160.872

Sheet: BSP Pipe Threads
M Q | Roscas de tubo BSP |  | Sort Order - 19 |  | External |  |  |  |  |  |  | Internal
 |  |  |  |  |  | Major Dia |  | Pitch Dia |  | Minor Dia |  |  | Minor Dia |  | Pitch Dia |  | Major Dia |  | Tap Drill | Thread Depth | Thread Runouts
Size | Size Suffix | Thread Designation | Custom Thread Designation | TPI | Class | Max | Min | Max | Min | Max | Min | Class | Min | Max | Min | Max | Min | Max | Basic |  | Basic
1/16 |  | G 1/16-28 | G 1/16-28 | 28 | A | 7.723 | 7.509 | 7.142 | 7.035 | 6.561 |  |  | 6.561 | 6.834 | 7.142 | 7.249 | 7.723 |  | 6.6000 | 15.4460 | 4.5000
1/16 |  | G 1/16-28 | G 1/16-28 | 28 | B | 7.723 | 7.509 | 7.142 | 7.035 | 6.561
1/8 |  | G 1/8-28 | G 1/8-28 | 28 | A | 9.728 | 9.514 | 9.147 | 9.040 | 8.566 |  |  | 8.566 | 8.848 | 9.147 | 9.254 | 9.728 |  | 8.7300 | 19.4560 | 4.5000
1/8 |  | G 1/8-28 | G 1/8-28 | 28 | B | 9.728 | 9.514 | 9.147 | 9.040 | 8.566
1/4 |  | G 1/4-19 | G 1/4-19 | 19 | A | 13.157 | 12.907 | 12.301 | 12.176 | 11.445 |  |  | 11.445 | 11.89 | 12.301 | 12.426 | 13.157 |  | 11.8000 | 26.3140 | 6.5000
1/4 |  | G 1/4-19 | G 1/4-19 | 19 | B | 13.157 | 12.907 | 12.301 | 12.176 | 11.445
3/8 |  | G 3/8-19 | G 3/8-19 | 19 | A | 16.662 | 16.412 | 15.806 | 15.681 | 14.950 |  |  | 14.95 | 15.395 | 15.806 | 15.931 | 16.662 |  | 15.2500 | 33.3240 | 6.5000
3/8 |  | G 3/8-19 | G 3/8-19 | 19 | B | 16.662 | 16.412 | 15.806 | 15.681 | 14.950
1/2 |  | G 1/2-14 | G 1/2-14 | 14 | A | 20.955 | 20.671 | 19.793 | 19.651 | 18.631 |  |  | 18.631 | 19.172 | 19.793 | 19.935 | 20.955 |  | 19.0500 | 41.9100 | 8.5000
1/2 |  | G 1/2-14 | G 1/2-14 | 14 | B | 20.955 | 20.671 | 19.793 | 19.651 | 18.631
5/8 |  | G 5/8-14 | G 5/8-14 | 14 | A | 22.911 | 22.627 | 21.749 | 21.607 | 20.587 |  |  | 20.587 | 21.128 | 21.749 | 21.891 | 22.911 |  | 21.0000 | 45.8220 | 8.5000
5/8 |  | G 5/8-14 | G 5/8-14 | 14 | B | 22.911 | 22.627 | 21.749 | 21.607 | 20.587
3/4 |  | G 3/4-14 | G 3/4-14 | 14 | A | 26.441 | 26.157 | 25.279 | 25.137 | 24.117 |  |  | 24.117 | 24.658 | 25.279 | 25.421 | 26.441 |  | 24.5000 | 52.8820 | 8.5000
3/4 |  | G 3/4-14 | G 3/4-14 | 14 | B | 26.441 | 26.157 | 25.279 | 25.137 | 24.117
7/8 |  | G 7/8-14 | G 7/8-14 | 14 | A | 30.201 | 29.917 | 29.039 | 28.897 | 27.877 |  |  | 27.877 | 28.418 | 29.039 | 29.181 | 30.201 |  | 28.2500 | 60.4020 | 8.5000
7/8 |  | G 7/8-14 | G 7/8-14 | 14 | B | 30.201 | 29.917 | 29.039 | 28.897 | 27.877
1 |  | G 1-11 | G 1-11 | 11 | A | 33.249 | 32.889 | 31.770 | 31.590 | 30.291 |  |  | 30.291 | 30.931 | 31.77 | 31.95 | 33.249 |  | 30.7500 | 66.4980 | 10.0000
1 |  | G 1-11 | G 1-11 | 11 | B | 33.249 | 32.889 | 31.770 | 31.590 | 30.291
1 1/4 |  | G 1 1/4-11 | G 1 1/4-11 | 11 | A | 41.910 | 41.550 | 40.431 | 40.251 | 38.952 |  |  | 38.952 | 39.592 | 40.431 | 40.611 | 41.910 |  | 39.5000 | 83.8200 | 10.0000
1 1/4 |  | G 1 1/4-11 | G 1 1/4-11 | 11 | B | 41.910 | 41.550 | 40.431 | 40.251 | 38.952
1 1/2 |  | G 1 1/2-11 | G 1 1/2-11 | 11 | A | 47.803 | 47.443 | 46.324 | 46.144 | 44.845 |  |  | 44.845 | 45.485 | 46.324 | 46.504 | 47.803 |  | 45.5000 | 95.6060 | 10.0000
1 1/2 |  | G 1 1/2-11 | G 1 1/2-11 | 11 | B | 47.803 | 47.443 | 46.324 | 46.144 | 44.845
1 3/4 |  | G 1 3/4-11 | G 1 3/4-11 | 11 | A | 53.746 | 53.386 | 52.267 | 52.087 | 50.788 |  |  | 50.788 | 51.428 | 52.267 | 52.447 | 53.746 |  | 51.0000 | 107.4920 | 10.0000
1 3/4 |  | G 1 3/4-11 | G 1 3/4-11 | 11 | B | 53.746 | 53.386 | 52.267 | 52.087 | 50.788
2 |  | G 2-11 | G 2-11 | 11 | A | 59.614 | 59.254 | 58.135 | 57.955 | 56.656 |  |  | 56.656 | 57.296 | 58.135 | 58.315 | 59.614 |  | 57.0000 | 119.2280 | 10.0000
2 |  | G 2-11 | G 2-11 | 11 | B | 59.614 | 59.254 | 58.135 | 57.955 | 56.656
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

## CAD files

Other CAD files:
Cads/Herramienta/Templates/English/ANSI (in).dwg
Cads/Herramienta/Templates/Metric/GB.dwg
Cads/Herramienta/Templates/Standard.dwg
Cads/Herramienta/Templates/Metric/JIS.dwg
Cads/Herramienta/Templates/Metric/ISO.dwg
Cads/Herramienta/Templates/Metric/BSI.dwg
Cads/Herramienta/Templates/Metric/ANSI (mm).dwg
Cads/Herramienta/Templates/Metric/DIN.dwg
Cads/Herramienta/Templates/Metric/GOST.dwg
Cads/Herramienta/20-15 (2.5kg 12V).ipt
Cads/Herramienta/Design Data/AIT/Mold Design/mold design stop pin.ipt
Cads/Herramienta/Design Data/Cable & Harness/es-ES/harness.iam
Cads/Herramienta/Design Data/Tube & Pipe/es-ES/piping runs.iam
Cads/Herramienta/Ensamblaje.iam
Cads/Herramienta/Primer parte.ipt
Cads/Herramienta/SegundaParte.ipt
Cads/Herramienta/TeceraParte.ipt
Cads/Herramienta/Templates/English/ANSI (in).idw
Cads/Herramienta/Templates/English/Mold Design (in).iam
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
